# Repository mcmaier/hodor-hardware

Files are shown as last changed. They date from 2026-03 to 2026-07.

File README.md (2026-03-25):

# HODOR - Highly flexible Open-source Door Operation Regulator

## Overview

HODOR ("Holds your door") is a universal controller for sliding door motor systems. The device is designed to operate brushed DC motors ranging from 12 to 24V, providing a comprehensive control solution that can be configured via Wi-Fi for smart home integration.

The hardware design files were created in KiCAD 9.0.

## System Architecture

The HODOR system consists of four main subsystems:

1. **Controllerboard** - Central processing unit based on the ESP32-S3
2. **Power Supply** - Handles voltage regulation and power distribution
3. **Motor Control** - Manages motor drive with H-bridge driver and feedback systems
4. **Peripherals** - Provides additional I/O and integration capabilities

### Block Diagram

```
+---------------+    +----------------+
|    Power      |    |                |
|   Terminals   |----| Controllerboard|
|   12-24V      |    |   (ESP32-S3)   |<--->[SPI BUS]
+---------------+    |                |
                     |                |----+
                     +----------------+    |
                            ^              |
                            |              v
                            |        +----------------+
                            |        |  Peripherals   |
                            |        +----------------+
                            v
                     +----------------+
                     |  Motor Control |
                     |   H-Bridge     |
                     |   Encoder I/F  |
                     +----------------+
```

## Technical Specifications

| Input Voltage | Standby Current |
|---|---|
| 12 V | tbc |
| 24 V | tbc |

## Subsystems

### Controller Board (ESP32-S3)

The central controller is based on an ESP32-S3 microcontroller that handles:
- Motor control with PWM outputs
- Safety monitoring
- Encoder feedback processing
- SPI communication with peripherals
- Wi-Fi connectivity for configuration and smart home integration

The controller connects to both the motor control subsystem and peripheral I/O expansion modules through a combination of digital signals and an SPI bus.

### Power Supply

The power subsystem converts the 12-24V input to the required voltages for the control circuits and provides:
- Input voltage sensing (`V_BUS_SENSE`)
- DC-link voltage monitoring (`V_DC_SENSE`)
- Protection circuitry

### Motor Control

The motor control subsystem features:
- H-bridge driver with PWM inputs (`DRV_PWM1`, `DRV_PWM2`)
- Driver enable control (`DRV_EN`)
- Fault monitoring (`DRV_~SF`)
- Safety trigger and clear mechanisms (`SAFETY_TRIG`, `SAFETY_~CLR`)
- Current sensing (`ADC_I_SENSE`, `ADC_DRV_FB`)
- Quadrature encoder interface (`ENCODER_A`, `ENCODER_B`)
- An independet brake chopper, that burns voltage peaks above 27 V, to protect the driver IC.

The H-bridge allows bidirectional control of the DC motor with variable speed control via PWM.

### Peripherals

The control device provides:
- Inputs (Potential free or 12..24 V DC)
- Status indicators
- Relay output

## Key Features

- Supports brushed DC motors from 12 to 24V
- H-bridge driver with current sensing for motor protection
- Quadrature encoder interface for precise position feedback
- Configurable inputs
- Programmable relay output
- Wi-Fi connectivity for configuration and smart home integration
- Safety mechanisms for door operation
- Open-source hardware and software design

## Applications

The HODOR controller is primarily designed for:
- Sliding door automation
- Other motor control applications with optional position feedback

## Project Status

This project is currently in development.

## Safety Features

HODOR incorporates several safety features:
- Current monitoring to detect obstructions
- Position feedback via quadrature encoder
- Hardware watchdog safety trigger 
- Fault detection in the motor driver

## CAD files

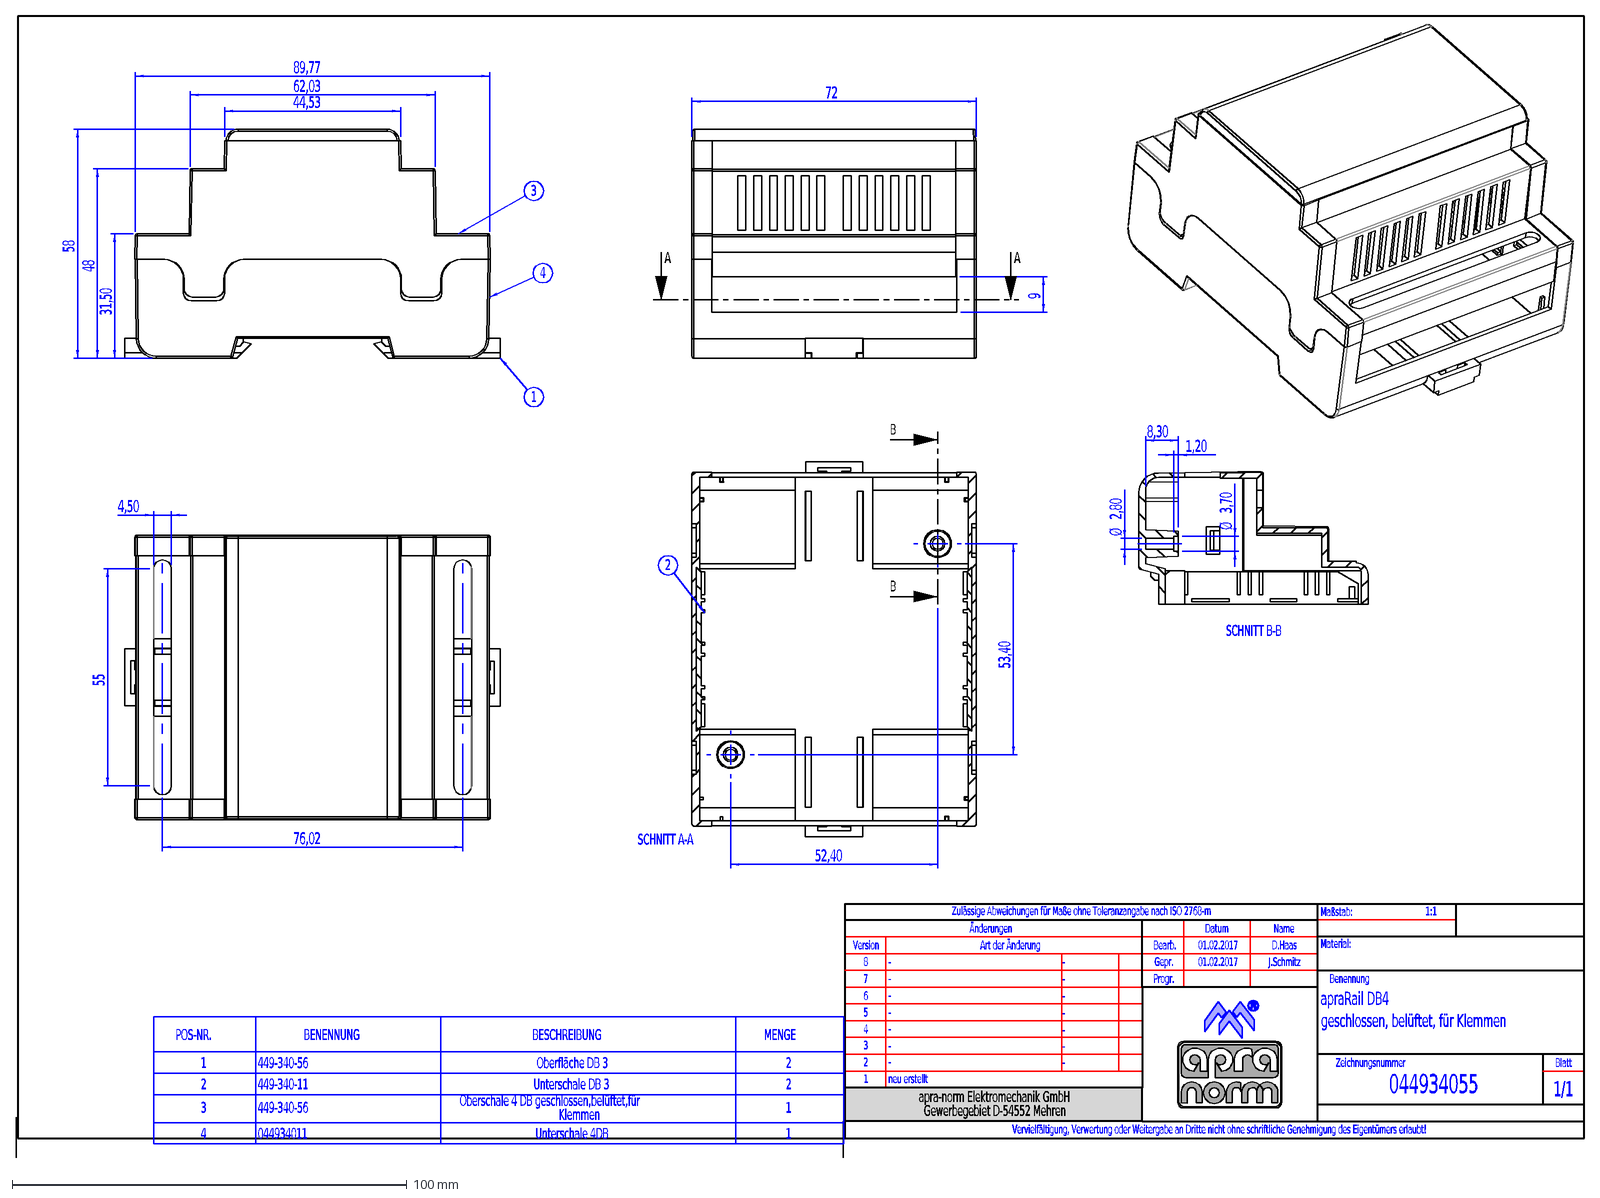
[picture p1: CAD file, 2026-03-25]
mechanics/apra_Rail_DB4.DXF
-
1/1
044934055
geschlossen, belüftet, für Klemmen
apraRail DB4
01.02.2017
D.Haas
J.Schmitz
neu erstellt
Vervielfältigung, Verwertung oder Weitergabe an Dritte nicht ohne schriftliche Genehmigung des Eigentümers erlaubt!
Maßstab:
Material:
Benennung
Zeichnungsnummer
Blatt
Zulässige Abweichungen für Maße ohne Toleranzangabe nach ISO 2768-m
Name
Datum
Bearb.
Gepr.
Progr.
Änderungen
Art der Änderung
Version
8
7
4
5
6
1
2
3
apra-norm Elektromechanik GmbH
Gewerbegebiet D-54552 Mehren
1:1
POS-NR.
BENENNUNG
BESCHREIBUNG
MENGE
449-340-56
Oberfläche DB 3
449-340-11
Unterschale DB 3
Oberschale 4 DB geschlossen,belüftet,für
Klemmen
044934011
Unterschale 4DB
89,77
62,03
44,53
31,50
48
58
72
9
A
4,50
55
76,02
52,40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

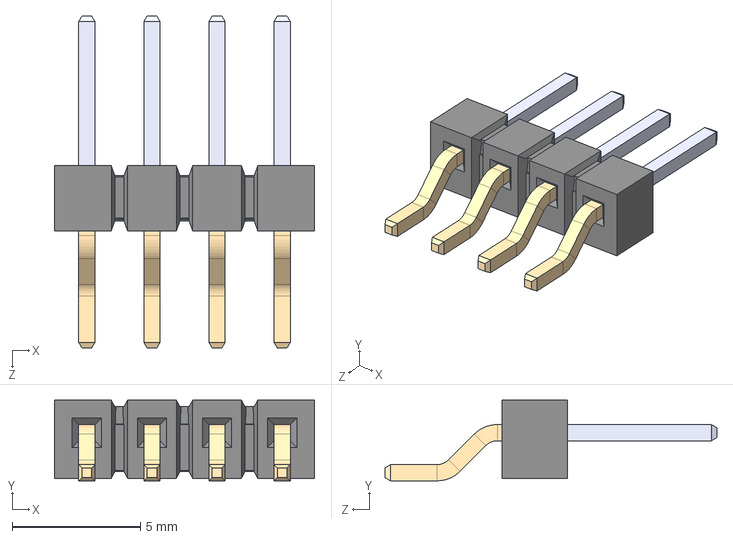
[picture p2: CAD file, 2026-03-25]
mechanics/TSM-104-01-L-SH--3DModel-STEP-56544.STEP
10.2 x 3.15 x 13.0 mm

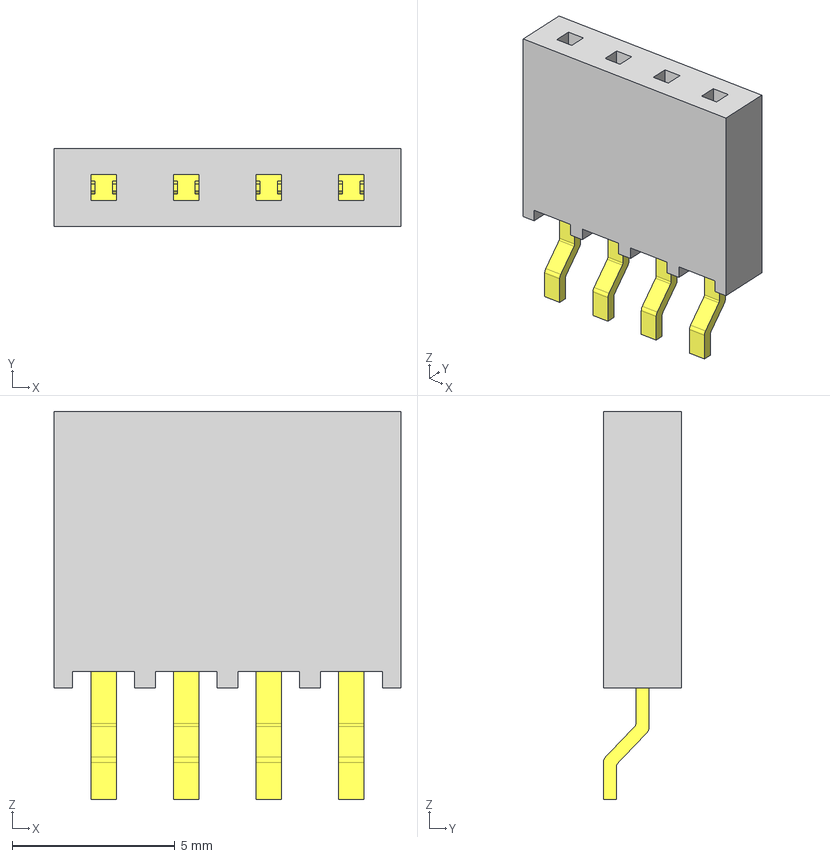
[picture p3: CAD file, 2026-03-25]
mechanics/SMH-104-02-G-S.stp
10.7 x 2.41 x 11.9 mm
SMH-104-S_socket
C-08-03-04-S_SMH

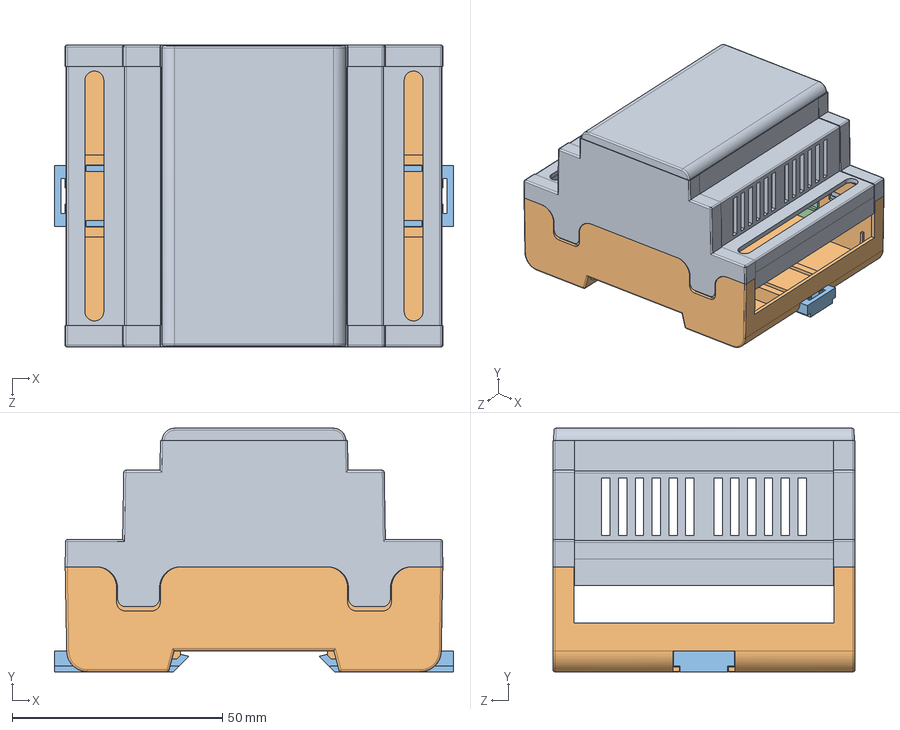
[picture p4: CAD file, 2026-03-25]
mechanics/449-340-55.STEP
95.0 x 58.0 x 72.0 mm
044934056s
044934011s
044900300s x 2
044900400s x 2

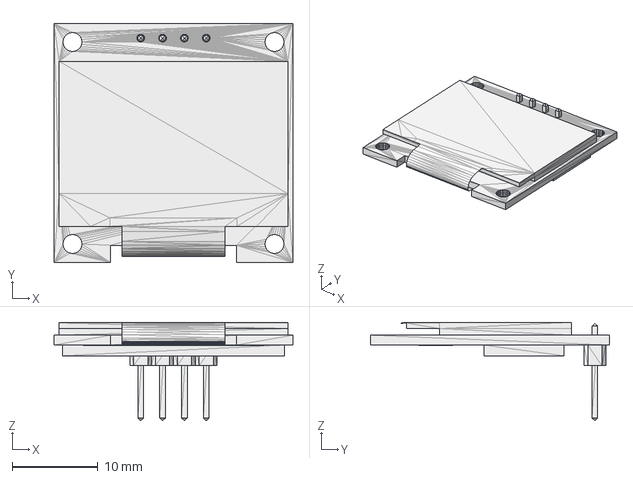
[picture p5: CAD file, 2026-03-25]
mechanics/SSD1306_OLED.step
27.8 x 27.8 x 11.4 mm

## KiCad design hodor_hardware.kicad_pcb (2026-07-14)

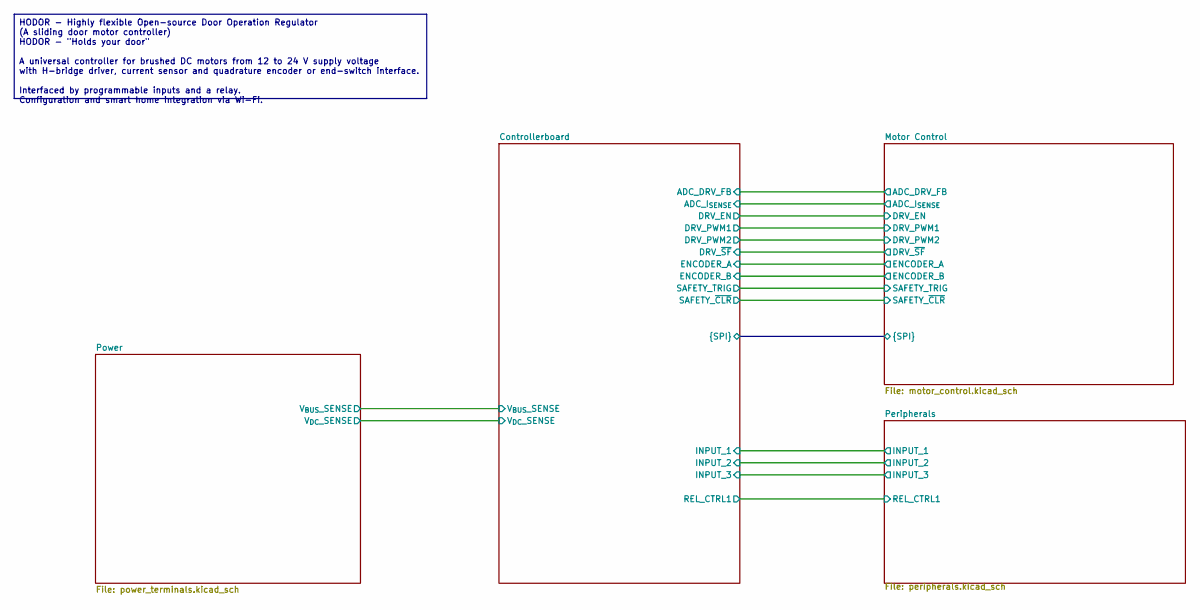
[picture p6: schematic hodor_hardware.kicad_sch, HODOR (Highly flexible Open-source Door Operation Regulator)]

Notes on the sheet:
HODOR - Highly flexible Open-source Door Operation Regulator (A sliding door motor controller) HODOR - "Holds your door" A universal controller for brushed DC motors from 12 to 24 V supply voltage with H-bridge driver, current sensor and quadrature encoder or end-switch interface. Interfaced by pro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

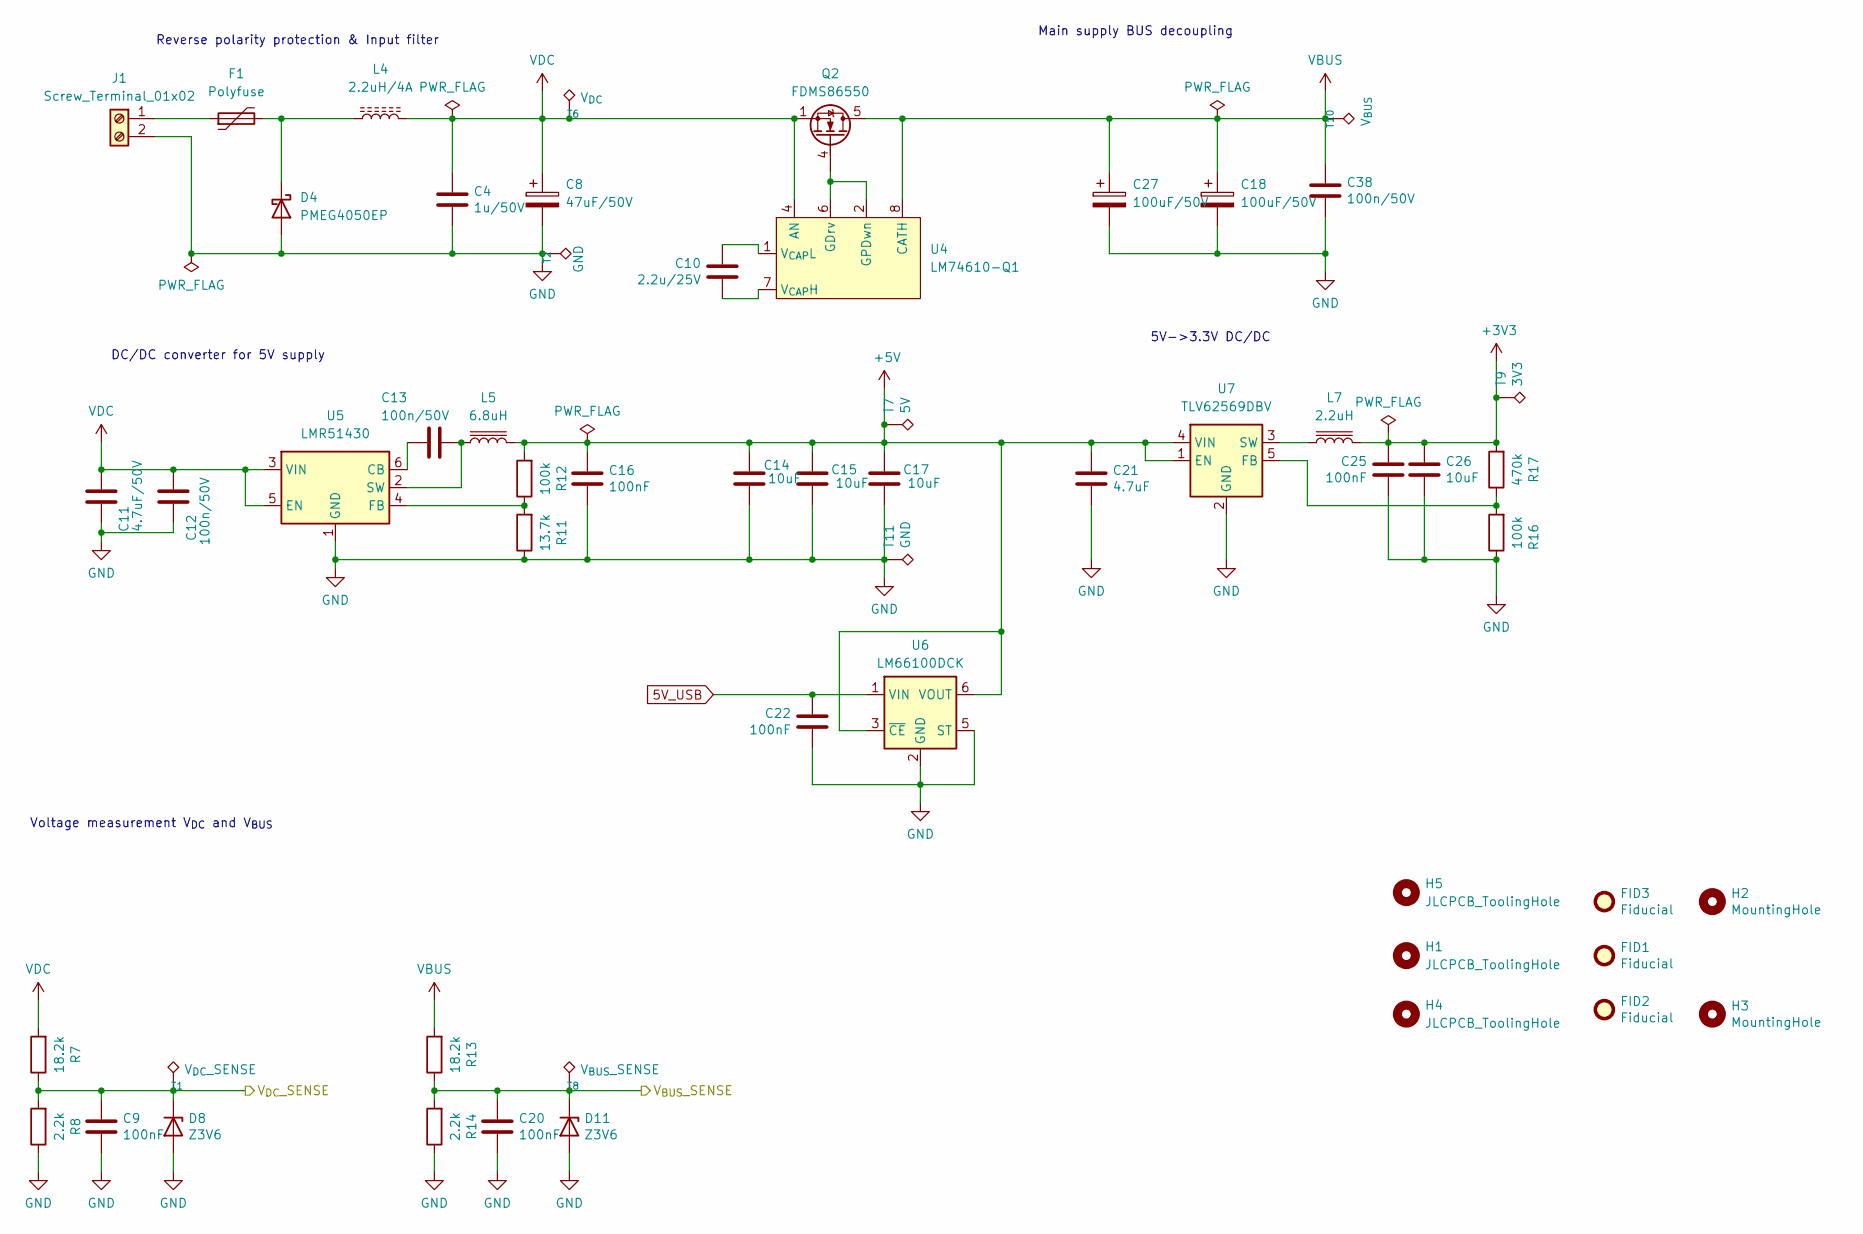
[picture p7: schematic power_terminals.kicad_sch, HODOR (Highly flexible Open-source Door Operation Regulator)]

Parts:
C4: 1u/50V; C_0805_2012Metric
C8: 47uF/50V; CP_Elec_6.3x5.8
C9, C16, C20, C22, C25: 100nF; C_0402_1005Metric
C10: 2.2u/25V; C_0805_2012Metric
C11: 4.7uF/50V; C_1206_3216Metric
C12, C13, C38: 100n/50V; C_0603_1608Metric
C14, C15, C17, C26: 10uF; C_0805_2012Metric
C18, C27: 100uF/50V; C_Elec_8x10.2
C21: 4.7uF; C_1206_3216Metric
D4: PMEG4050EP; D_SOD-128
D8, D11: Z3V6; D_SOD-523
F1: Polyfuse; Fuse_2920_7451Metric
FID1, FID2, FID3: Fiducial; Fiducial_1mm_Mask2mm
H1, H4, H5: JLCPCB_ToolingHole
H2, H3: MountingHole; MountingHole_3.2mm_M3
J1: Screw_Terminal_01x02; TerminalBlock_Phoenix_MKDS-1,5-2_1x02_P5.00mm_Horizontal
L4: 2.2uH/4A; L_Wuerth_MAPI-4020
L5: 6.8uH; L_Wuerth_WE-PD2-Typ-MS
L7: 2.2uH; L_1812_4532Metric
Q2: FDMS86550; TDSON-8-1
R7, R13: 18.2k; R_0402_1005Metric
R8, R14: 2.2k; R_0402_1005Metric
R11: 13.7k; R_0402_1005Metric
R12, R16: 100k; R_0402_1005Metric
R17: 470k; R_0402_1005Metric
T1: V_{DC}_SENSE; TestPoint_Pad_D1.0mm
T2, T11: GND; TestPoint_Pad_1.0x1.0mm
T6: V_{DC}; TestPoint_Pad_D1.0mm
T7: 5V; TestPoint_Pad_D1.0mm
T8: V_{BUS}_SENSE; TestPoint_Pad_D1.0mm
T9: 3V3; TestPoint_Pad_D1.0mm
T10: V_{BUS}; TestPoint_Pad_D1.0mm
U4: LM74610-Q1; VSSOP-8_3x3mm_P0.65mm
U5: LMR51430; SOT-23-6
U6: LM66100DCK; SOT-363_SC-70-6
U7: TLV62569DBV; SOT-23-5

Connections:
5V_USB: C22.2, U6.1 (VIN); also elsewhere on the board
+3V3: C25.1, C26.1, L7.2, R17.2, T9.1; also elsewhere on the board
+5V: C14.1, C15.1, C16.1, C17.1, C21.1, L5.2, R12.2, T7.1, U6.3 (~CE), U6.6 (VOUT), U7.1 (EN), U7.4 (VIN); also elsewhere on the board
/Controllerboard/V_{BUS}_SENSE: C20.1, D11.1 (K), R13.1, R14.2, T8.1; also elsewhere on the board
/Controllerboard/V_{DC}_SENSE: C9.1, D8.1 (K), R7.1, R8.2, T1.1; also elsewhere on the board
GND: C4.2, C8.2, C9.2, C11.2, C12.2, C14.2, C15.2, C16.2, C17.2, C18.2, C20.2, C21.2, C22.1, C25.2, C26.2, C27.2, C38.2, D4.2 (A), D8.2 (A), D11.2 (A), J1.2, R8.1, R11.1, R14.1, R16.1, T2.1, T11.1, U5.1 (GND), U6.2 (GND), U6.5 (ST), U7.2 (GND); also elsewhere on the board
unnamed: D4.1 (K), F1.2, L4.1
unnamed: F1.1, J1.1
unnamed: Q2.4 (G), U4.2 (GPDwn), U4.6 (GDrv)
unnamed: C10.2, U4.7 (V_{CAP}H)
unnamed: C10.1, U4.1 (V_{CAP}L)
unnamed: C13.2, U5.6 (CB)
unnamed: R11.2, R12.1, U5.4 (FB)
unnamed: C13.1, L5.1, U5.2 (SW)
unnamed: R16.2, R17.1, U7.5 (FB)
unnamed: L7.1, U7.3 (SW)
VBUS: C18.1, C27.1, C38.1, Q2.5 (D), R13.2, T10.1, U4.8 (CATH); also elsewhere on the board
VDC: C4.1, C8.1, C11.1, C12.1, L4.2, Q2.1 (S), Q2.2 (S), Q2.3 (S), R7.2, T6.1, U4.4 (AN), U5.3 (VIN), U5.5 (EN)

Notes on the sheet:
DC/DC converter for 5V supply
5V->3.3V DC/DC
Voltage measurement V_{DC} and V_{BUS}
Reverse polarity protection & Input filter
Main supply BUS decoupling

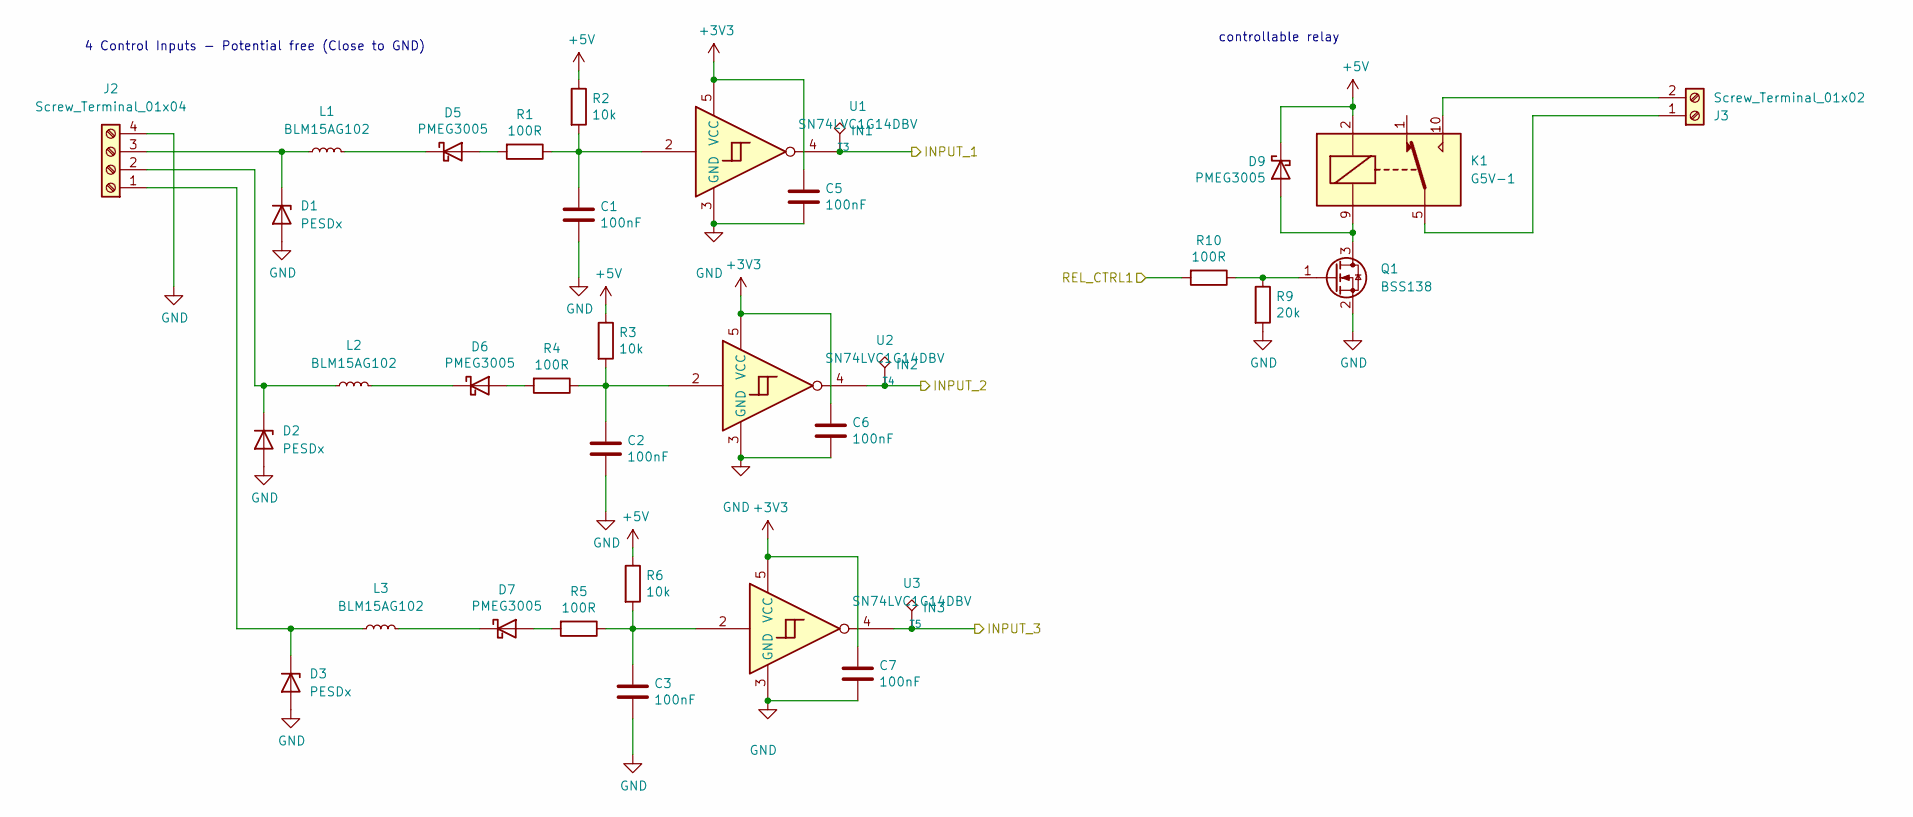
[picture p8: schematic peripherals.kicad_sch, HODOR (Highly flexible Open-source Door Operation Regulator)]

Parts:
C1, C2, C3, C5, C6, C7: 100nF; C_0402_1005Metric
D1, D2, D3: PESDx; D_SOD-523
D5, D6, D7, D9: PMEG3005; D_SOD-523
J2: Screw_Terminal_01x04; TerminalBlock_Phoenix_MKDS-1,5-4_1x04_P5.00mm_Horizontal
J3: Screw_Terminal_01x02; TerminalBlock_Phoenix_MKDS-1,5-2_1x02_P5.00mm_Horizontal
K1: G5V-1; Relay_SPDT_Omron_G5V-1
L1, L2, L3: BLM15AG102; L_0402_1005Metric
Q1: BSS138; SOT-23
R1, R4, R5, R10: 100R; R_0402_1005Metric
R2, R3, R6: 10k; R_0402_1005Metric
R9: 20k; R_0402_1005Metric
T3: IN1; TestPoint_Pad_D1.0mm
T4: IN2; TestPoint_Pad_D1.0mm
T5: IN3; TestPoint_Pad_D1.0mm
U1, U2, U3: SN74LVC1G14DBV; SOT-23-5

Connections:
+3V3: C5.1, C6.1, C7.1, U1.5 (VCC), U2.5 (VCC), U3.5 (VCC); also elsewhere on the board
+5V: D9.1 (K), K1.2, R2.1, R3.1, R6.1; also elsewhere on the board
/Controllerboard/INPUT_1: T3.1, U1.4; also elsewhere on the board
/Controllerboard/INPUT_2: T4.1, U2.4; also elsewhere on the board
/Controllerboard/INPUT_3: T5.1, U3.4; also elsewhere on the board
/Controllerboard/REL_CTRL1: R10.2; also elsewhere on the board
GND: C1.2, C2.2, C3.2, C5.2, C6.2, C7.2, D1.2 (A), D2.2 (A), D3.2 (A), J2.4, Q1.2 (S), R9.2, U1.3 (GND), U2.3 (GND), U3.3 (GND); also elsewhere on the board
unnamed: C1.1, R1.1, R2.2, U1.2
unnamed: C2.1, R3.2, R4.1, U2.2
unnamed: C3.1, R5.1, R6.2, U3.2
unnamed: D1.1 (K), J2.3, L1.1
unnamed: D2.1 (K), J2.2, L2.1
unnamed: D3.1 (K), J2.1, L3.1
unnamed: D5.2 (A), R1.2
unnamed: D5.1 (K), L1.2
unnamed: D6.2 (A), R4.2
unnamed: D6.1 (K), L2.2
unnamed: D7.2 (A), R5.2
unnamed: D7.1 (K), L3.2
unnamed: D9.2 (A), K1.9, Q1.3 (D)
unnamed: J3.1, K1.5, K1.6
unnamed: J3.2, K1.10
unnamed: Q1.1 (G), R9.1, R10.1

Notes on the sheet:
4 Control Inputs - Potential free (Close to GND)
controllable relay

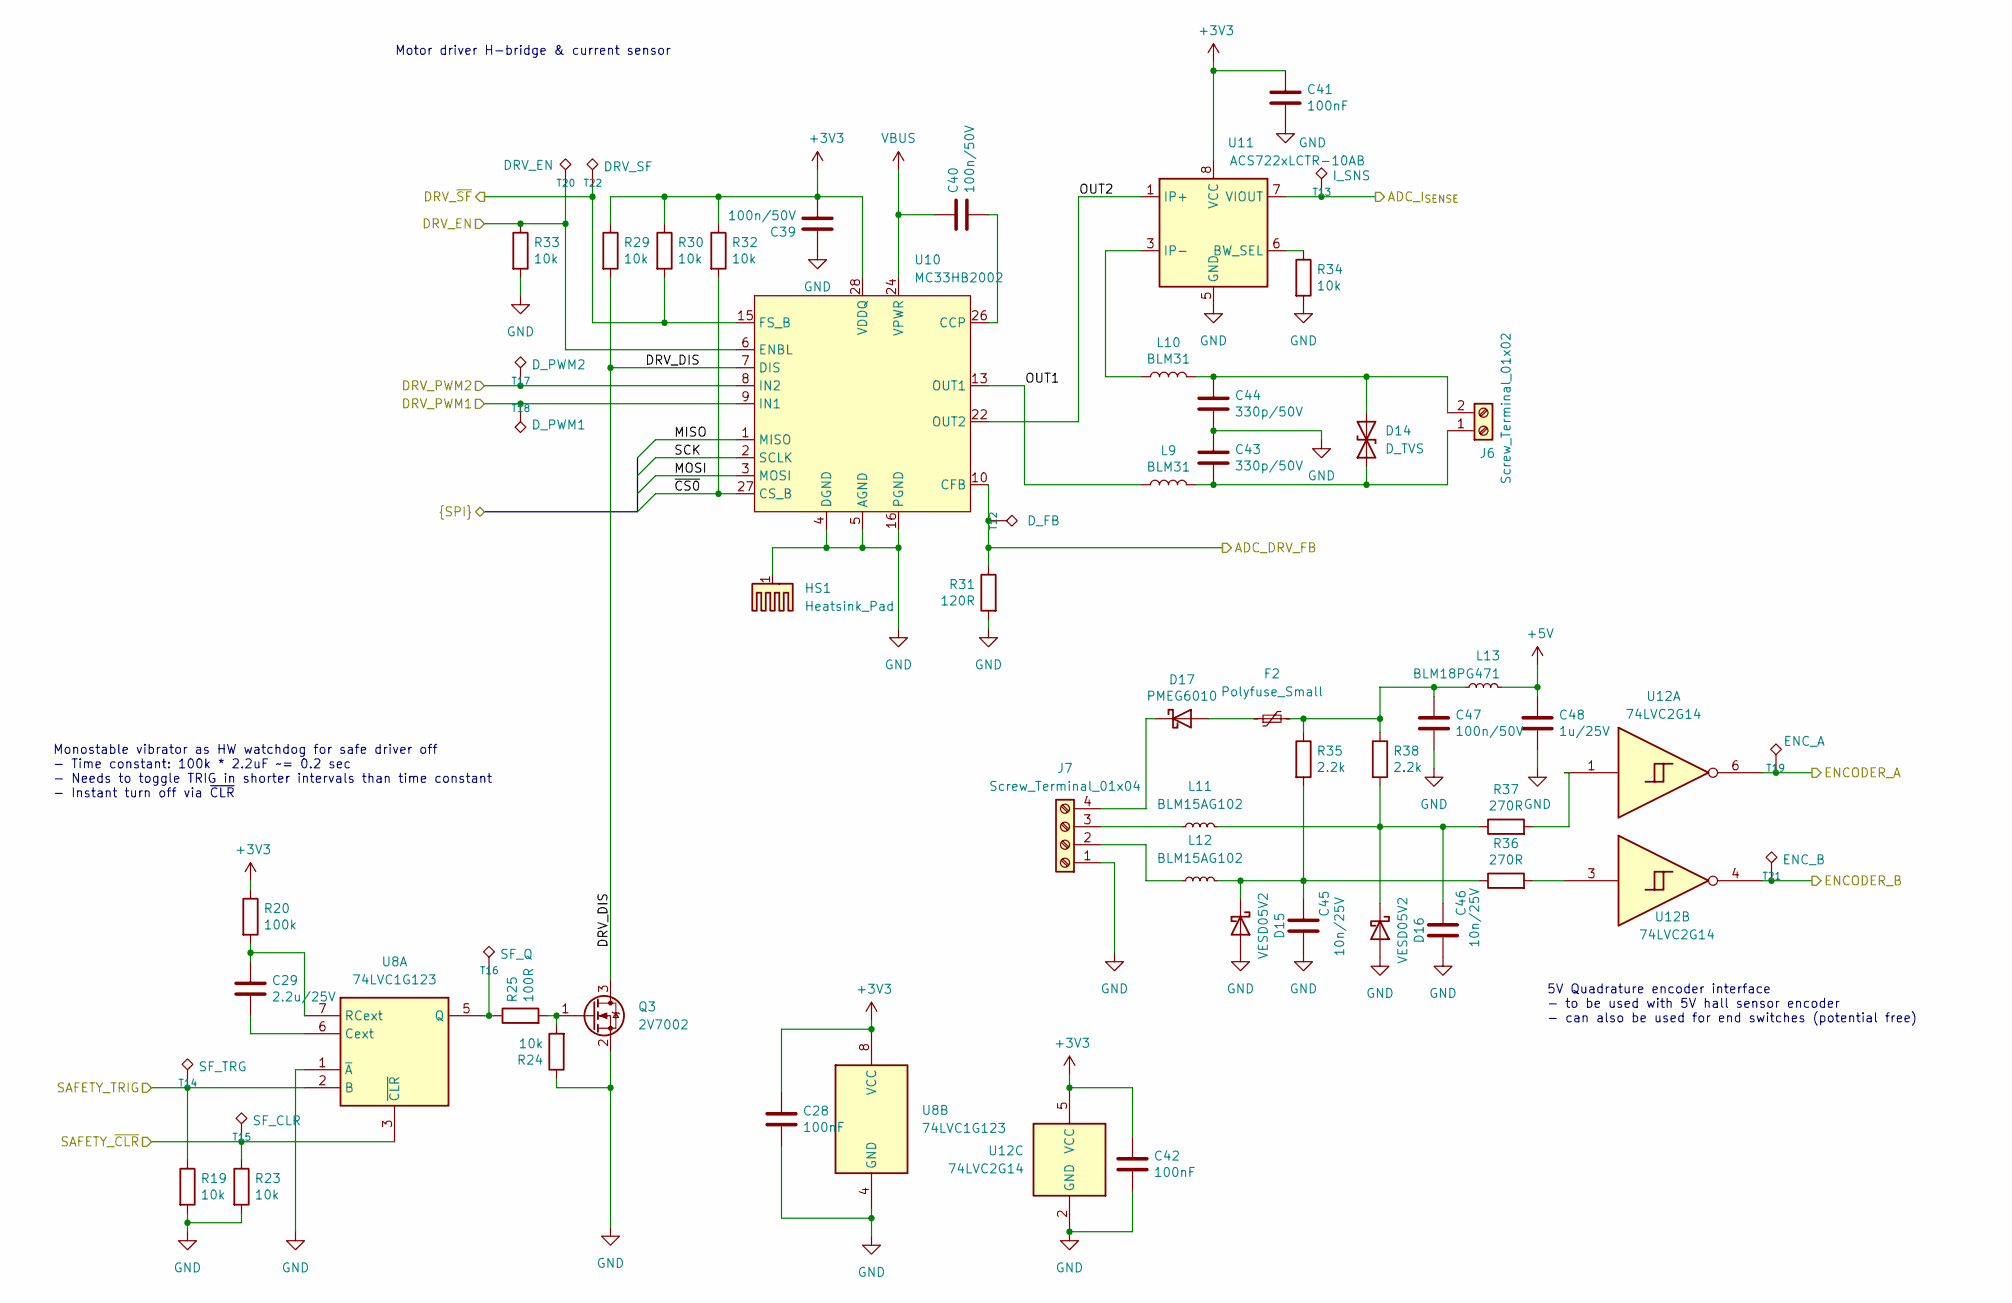
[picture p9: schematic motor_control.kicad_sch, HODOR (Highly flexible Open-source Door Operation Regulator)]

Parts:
C28, C41, C42: 100nF; C_0402_1005Metric
C29: 2.2u/25V; C_0805_2012Metric
C39, C40, C47: 100n/50V; C_0603_1608Metric
C43, C44: 330p/50V; C_0603_1608Metric
C45, C46: 10n/25V; C_0402_1005Metric
C48: 1u/25V; C_0603_1608Metric
D14: D_TVS; D_SMB
D15, D16: VESD05V2; D_SOD-523
D17: PMEG6010; D_SOD-123F
F2: Polyfuse_Small; Fuse_0805_2012Metric
HS1: Heatsink_Pad; Heatsink_AAVID_573300D00010G_TO-263
J6: Screw_Terminal_01x02; TerminalBlock_Phoenix_MKDS-1,5-2_1x02_P5.00mm_Horizontal
J7: Screw_Terminal_01x04; TerminalBlock_Phoenix_MKDS-1,5-4_1x04_P5.00mm_Horizontal
L9, L10: BLM31; L_1206_3216Metric
L11, L12: BLM15AG102; L_0402_1005Metric
L13: BLM18PG471; L_0603_1608Metric
Q3: 2V7002; SOT-323_SC-70
R19, R23, R24, R29, R30, R32, R33, R34: 10k; R_0402_1005Metric
R20: 100k; R_0402_1005Metric
R25: 100R; R_0402_1005Metric
R31: 120R; R_0603_1608Metric
R35, R38: 2.2k; R_0402_1005Metric
R36, R37: 270R; R_0402_1005Metric
T12: D_FB; TestPoint_Pad_D1.0mm
T13: I_SNS; TestPoint_Pad_D1.0mm
T14: SF_TRG; TestPoint_Pad_D1.0mm
T15: SF_CLR; TestPoint_Pad_D1.0mm
T16: SF_Q; TestPoint_Pad_D1.0mm
T17: D_PWM2; TestPoint_Pad_D1.0mm
T18: D_PWM1; TestPoint_Pad_D1.0mm
T19: ENC_A; TestPoint_Pad_D1.0mm
T20: DRV_EN; TestPoint_Pad_D1.0mm
T21: ENC_B; TestPoint_Pad_D1.0mm
T22: DRV_SF; TestPoint_Pad_D1.0mm
U8: 74LVC1G123; VSSOP-8_2.3x2mm_P0.5mm
U10: MC33HB2002; HVQFN-28-1EP_6x6mm_MC33HB2002
U11: ACS722xLCTR-10AB; SOIC-8_3.9x4.9mm_P1.27mm
U12: 74LVC2G14; SOT-23-6

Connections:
+3V3: C28.1, C39.2, C41.1, C42.1, R20.1, R29.1, R30.1, R32.1, U8.8 (VCC), U10.28 (VDDQ), U11.8 (VCC), U12.5 (VCC); also elsewhere on the board
+5V: C48.1, L13.2; also elsewhere on the board
/Controllerboard/ADC_DRV_FB: R31.1, T12.1, U10.10 (CFB); also elsewhere on the board
/Controllerboard/ADC_I_{SENSE}: T13.1, U11.7 (VIOUT); also elsewhere on the board
/Controllerboard/DRV_EN: R33.1, T20.1, U10.6 (ENBL); also elsewhere on the board
/Controllerboard/DRV_PWM1: T18.1, U10.9 (IN1); also elsewhere on the board
/Controllerboard/DRV_PWM2: T17.1, U10.8 (IN2); also elsewhere on the board
/Controllerboard/DRV_~SF: R30.2, T22.1, U10.15 (FS_B); also elsewhere on the board
/Controllerboard/ENCODER_A: T19.1, U12.6; also elsewhere on the board
/Controllerboard/ENCODER_B: T21.1, U12.4; also elsewhere on the board
/Controllerboard/MISO: U10.1 (MISO); also elsewhere on the board
/Controllerboard/MOSI: U10.3 (MOSI); also elsewhere on the board
/Controllerboard/SAFETY_TRIG: R19.1, T14.1, U8.2 (B); also elsewhere on the board
/Controllerboard/SAFETY_~CLR: R23.1, T15.1, U8.3 (~CLR); also elsewhere on the board
/Controllerboard/SCK: U10.2 (SCLK); also elsewhere on the board
/Controllerboard/~CS0: R32.2, U10.27 (CS_B); also elsewhere on the board
/Motor Control/DRV_DIS: Q3.3 (D), R29.2, U10.7 (DIS)
/Motor Control/OUT1: L9.1, U10.13 (OUT1), U10.14 (OUT1)
/Motor Control/OUT2: U10.22 (OUT2), U10.23 (OUT2), U11.1 (IP+), U11.2 (IP+)
GND: C28.2, C39.1, C41.2, C42.2, C43.1, C44.2, C45.2, C46.2, C47.2, C48.2, D15.2 (A), D16.2 (A), HS1.1, J7.1, Q3.2 (S), R19.2, R23.2, R24.1, R31.2, R33.2, R34.2, U8.1 (~A), U8.4 (GND), U10.4 (DGND), U10.5 (AGND), U10.16 (PGND), U10.17 (PGND), U10.18 (PGND), U10.19 (PGND), U10.20 (PGND), U10.21 (AGND), U10.29 (AGND), U11.5 (GND), U12.2 (GND); also elsewhere on the board
unnamed: C47.1, F2.2, L13.1, R35.1, R38.1
unnamed: C43.2, D14.1 (A1), J6.1, L9.2
unnamed: C44.1, D14.2 (A2), J6.2, L10.2
unnamed: C45.1, D15.1 (K), L12.2, R35.2, R36.1
unnamed: C46.1, D16.1 (K), L11.2, R37.1, R38.2
unnamed: D17.2 (A), F2.1
unnamed: D17.1 (K), J7.4
unnamed: J7.2, L12.1
unnamed: J7.3, L11.1
unnamed: L10.1, U11.3 (IP-), U11.4 (IP-)
unnamed: Q3.1 (G), R24.2, R25.2
unnamed: R36.2, U12.3
unnamed: R37.2, U12.1
unnamed: C29.2, U8.6 (Cext)
unnamed: R25.1, T16.1, U8.5 (Q)
unnamed: C29.1, R20.2, U8.7 (RCext)
unnamed: C40.2, U10.26 (CCP)
unnamed: R34.1, U11.6 (BW_SEL)
VBUS: C40.1, U10.11 (VPWR), U10.12 (VPWR), U10.24 (VPWR), U10.25 (VPWR); also elsewhere on the board

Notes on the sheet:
5V Quadrature encoder interface - to be used with 5V hall sensor encoder - can also be used for end switches (potential free)
Motor driver H-bridge & current sensor
Monostable vibrator as HW watchdog for safe driver off - Time constant: 100k * 2.2uF ~= 0.2 sec - Needs to toggle TRIG in shorter intervals than time constant - Instant turn off via ~{CLR}

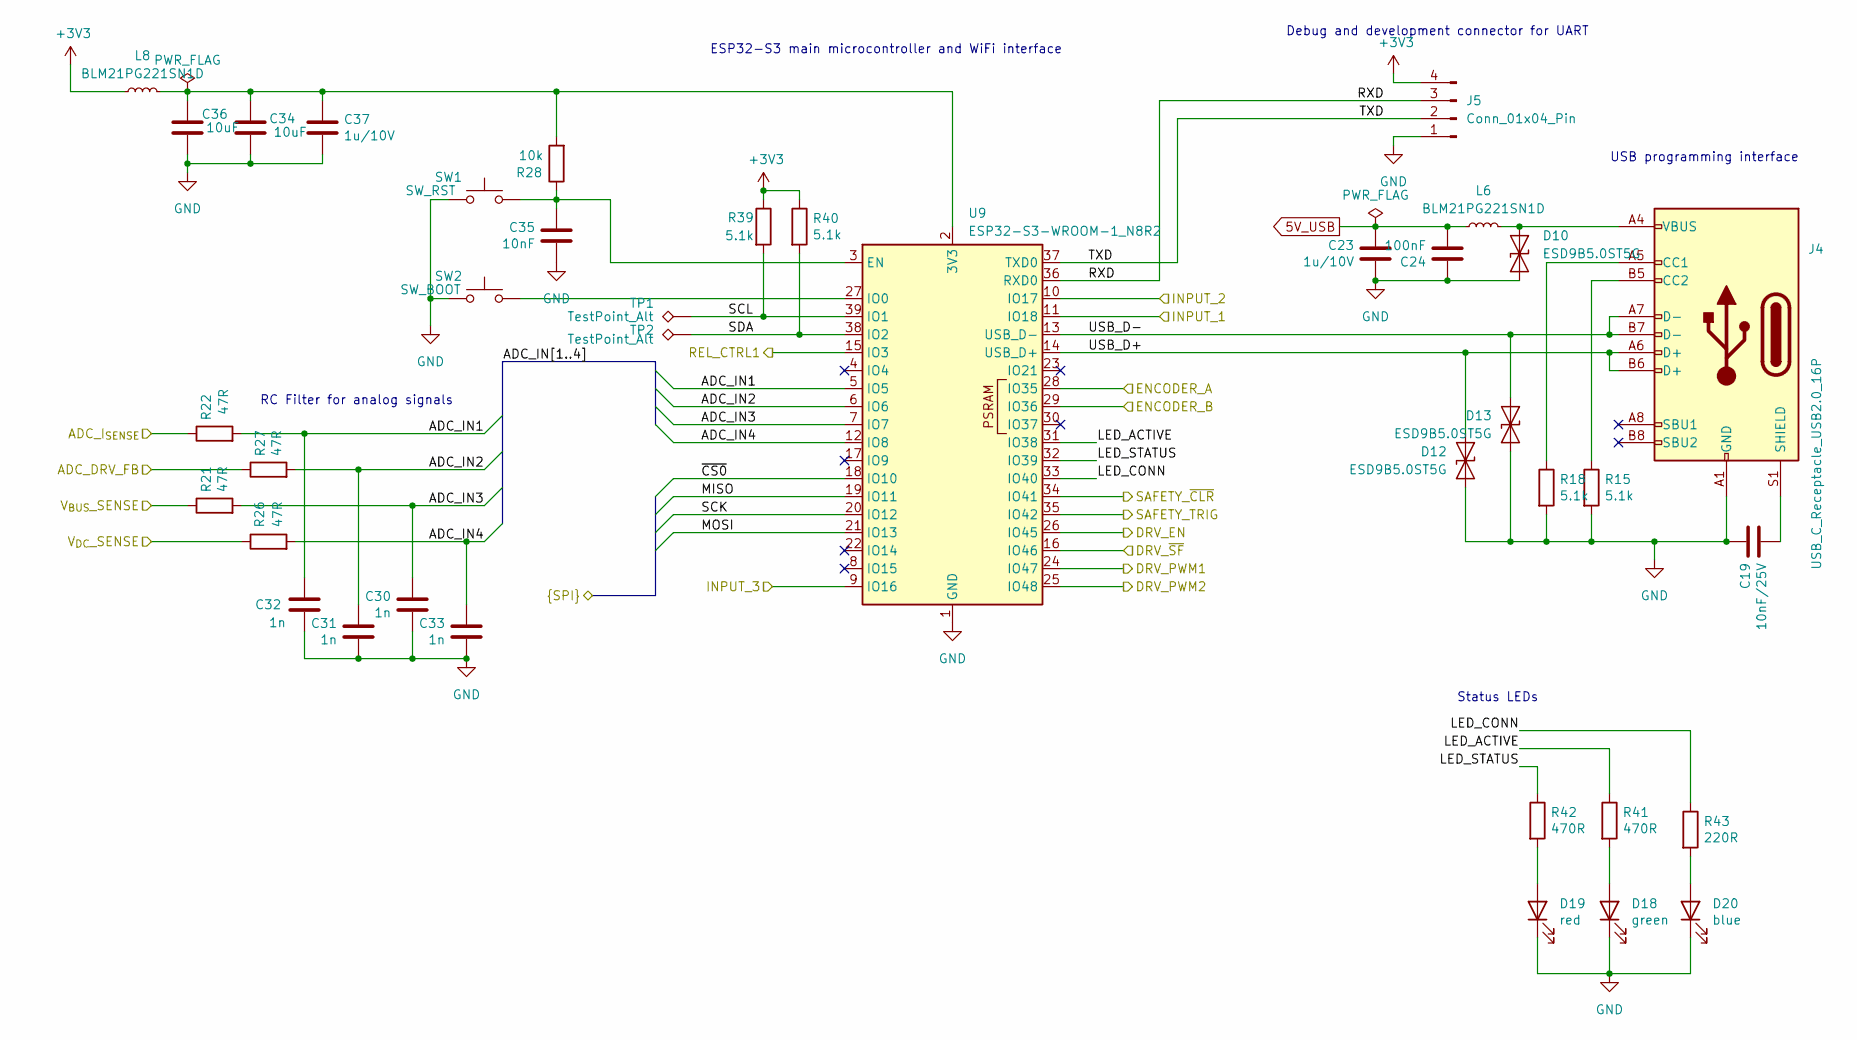
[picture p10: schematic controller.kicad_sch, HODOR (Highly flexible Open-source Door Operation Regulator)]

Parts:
C19: 10nF/25V; C_0402_1005Metric
C23, C37: 1u/10V; C_0402_1005Metric
C24: 100nF; C_0402_1005Metric
C30, C31, C32, C33: 1n; C_0402_1005Metric
C34, C36: 10uF; C_0805_2012Metric
C35: 10nF; C_0402_1005Metric
D10, D12, D13: ESD9B5.0ST5G; D_SOD-923
D18: green; LED_0603_1608Metric
D19: red; LED_0603_1608Metric
D20: blue; LED_0603_1608Metric
J4: USB_C_Receptacle_USB2.0_16P; USB_C_Receptacle_G-Switch_GT-USB-7010ASV
J5: Conn_01x04_Pin; PinHeader_1x04_P2.54mm_Vertical
L6, L8: BLM21PG221SN1D; L_0805_2012Metric
R15, R18, R39, R40: 5.1k; R_0402_1005Metric
R21, R22, R26, R27: 47R; R_0402_1005Metric
R28: 10k; R_0402_1005Metric
R41, R42: 470R; R_0402_1005Metric
R43: 220R; R_0402_1005Metric
SW1: SW_RST; SW_Push_SPST_NO_Alps_SKRK
SW2: SW_BOOT; SW_Push_SPST_NO_Alps_SKRK
TP1, TP2: TestPoint_Alt; TestPoint_Pad_1.0x1.0mm
U9: ESP32-S3-WROOM-1_N8R2; ESP32-S3-WROOM-1U

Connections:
5V_USB: C23.2, C24.1, L6.1; also elsewhere on the board
+3V3: J5.4, L8.1, R39.1, R40.1; also elsewhere on the board
/Controllerboard/ADC_DRV_FB: R27.1; also elsewhere on the board
/Controllerboard/ADC_IN1: C32.2, R22.2, U9.5 (IO5)
/Controllerboard/ADC_IN2: C31.2, R27.2, U9.6 (IO6)
/Controllerboard/ADC_IN3: C30.2, R21.2, U9.7 (IO7)
/Controllerboard/ADC_IN4: C33.2, R26.2, U9.12 (IO8)
/Controllerboard/ADC_I_{SENSE}: R22.1; also elsewhere on the board
/Controllerboard/DRV_EN: U9.26 (IO45); also elsewhere on the board
/Controllerboard/DRV_PWM1: U9.24 (IO47); also elsewhere on the board
/Controllerboard/DRV_PWM2: U9.25 (IO48); also elsewhere on the board
/Controllerboard/DRV_~SF: U9.16 (IO46); also elsewhere on the board
/Controllerboard/ENCODER_A: U9.28 (IO35); also elsewhere on the board
/Controllerboard/ENCODER_B: U9.29 (IO36); also elsewhere on the board
/Controllerboard/INPUT_1: U9.11 (IO18); also elsewhere on the board
/Controllerboard/INPUT_2: U9.10 (IO17); also elsewhere on the board
/Controllerboard/INPUT_3: U9.9 (IO16); also elsewhere on the board
/Controllerboard/LED_ACTIVE: R41.1, U9.31 (IO38)
/Controllerboard/LED_CONN: R43.1, U9.33 (IO40)
/Controllerboard/LED_STATUS: R42.1, U9.32 (IO39)
/Controllerboard/MISO: U9.19 (IO11); also elsewhere on the board
/Controllerboard/MOSI: U9.21 (IO13); also elsewhere on the board
/Controllerboard/REL_CTRL1: U9.15 (IO3); also elsewhere on the board
/Controllerboard/RXD: J5.3, U9.36 (RXD0)
/Controllerboard/SAFETY_TRIG: U9.35 (IO42); also elsewhere on the board
/Controllerboard/SAFETY_~CLR: U9.34 (IO41); also elsewhere on the board
/Controllerboard/SCK: U9.20 (IO12); also elsewhere on the board
/Controllerboard/SCL: R39.2, TP1.1, U9.39 (IO1)
/Controllerboard/SDA: R40.2, TP2.1, U9.38 (IO2)
/Controllerboard/TXD: J5.2, U9.37 (TXD0)
/Controllerboard/USB_D+: D12.2 (A2), J4.A6 (D+), J4.B6 (D+), U9.14 (USB_D+)
/Controllerboard/USB_D-: D13.2 (A2), J4.A7 (D-), J4.B7 (D-), U9.13 (USB_D-)
/Controllerboard/V_{BUS}_SENSE: R21.1; also elsewhere on the board
/Controllerboard/V_{DC}_SENSE: R26.1; also elsewhere on the board
/Controllerboard/~CS0: U9.18 (IO10); also elsewhere on the board
GND: C19.2, C23.1, C24.2, C30.1, C31.1, C32.1, C33.1, C34.2, C35.1, C36.2, C37.1, D10.1 (A1), D12.1 (A1), D13.1 (A1), D18.1 (K), D19.1 (K), D20.1 (K), J4.A1 (GND), J4.A12 (GND), J4.B1 (GND), J4.B12 (GND), J5.1, R15.2, R18.2, SW1.1, SW2.1, U9.1 (GND), U9.40 (GND), U9.41 (GND); also elsewhere on the board
unnamed: D10.2 (A2), J4.A4 (VBUS), J4.A9 (VBUS), J4.B4 (VBUS), J4.B9 (VBUS), L6.2
unnamed: D18.2 (A), R41.2
unnamed: D19.2 (A), R42.2
unnamed: D20.2 (A), R43.2
unnamed: J4.A5 (CC1), R18.1
unnamed: J4.B5 (CC2), R15.1
unnamed: C19.1, J4.S1 (SHIELD)
unnamed: C34.1, C36.1, C37.2, L8.2, R28.2, U9.2 (3V3)
unnamed: C35.2, R28.1, SW1.2, U9.3 (EN)
unnamed: SW2.2, U9.27 (IO0)

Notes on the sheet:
Status LEDs
RC Filter for analog signals
Debug and development connector for UART
ESP32-S3 main microcontroller and WiFi interface
USB programming interface

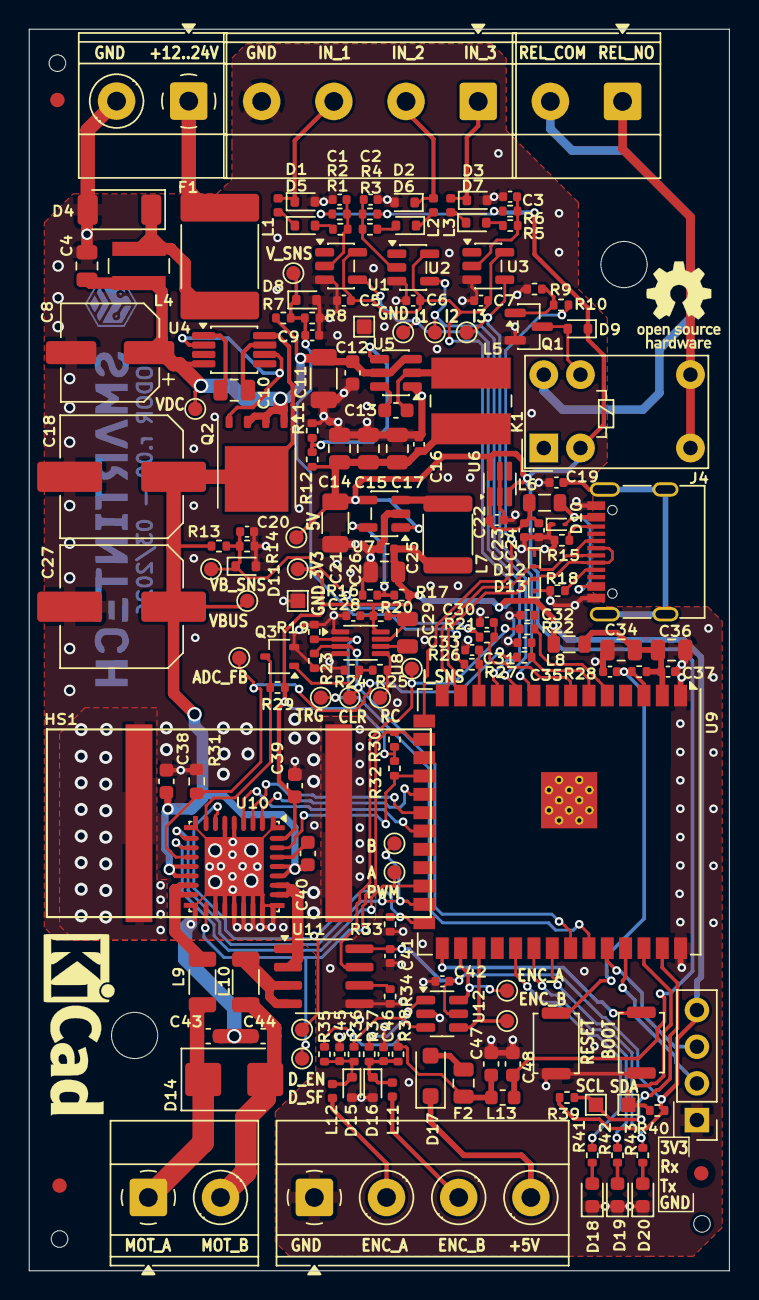
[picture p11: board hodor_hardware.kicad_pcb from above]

Board: 2 copper layers, 48.5 x 86.0 mm, 184 parts (0 on the bottom side), 96 nets.

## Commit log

2026-03-25 Initial commit: HODOR hardware design files (KiCad 9)
    [449-340-55.STEP, SMH-104-02-G-S.stp, SSD1306_OLED.step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]
2026-03-25 Simplified design (Old version switched to hodor-max)
    [controller.kicad_sch, hodor_hardware.kicad_pcb, hodor_hardware.kicad_sch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]
2026-03-27 All nets connected
    [controller.kicad_sch, hodor_hardware.kicad_pcb, power_terminals.kicad_sch]
2026-03-27 Finalized Layout
    [controller.kicad_sch, hodor_hardware.kicad_pcb, motor_control.kicad_sch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]
2026-07-14 Layout finished
    [hodor_hardware.kicad_pcb]

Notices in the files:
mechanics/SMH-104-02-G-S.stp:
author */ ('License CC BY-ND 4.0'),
